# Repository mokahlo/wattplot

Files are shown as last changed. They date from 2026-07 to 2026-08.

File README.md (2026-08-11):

# Wattplot







**One bed. Two harvests.**

A raised garden bed whose canopy is a working solar panel — the same
square foot grows tomatoes *and* generates electricity. Symbiosis of
energy production and agriculture: the plants get filtered afternoon
shade where they need it most; the panel keeps generating on a
structure that would have been lumber anyway.

Open-source end-to-end: 3D model, sun simulation, wind-load analysis,
cut lists, schematic (rev B), ESPHome firmware (v3.2), PCB layout, and
a GitHub Pages site. MIT license, no paywalls, no telemetry.

> **Status:** working prototype. The Mini v2.4 is built and running on
> the bench. The full-size build (Longi 620W) is mechanically and
> aerodynamically validated by FreeCAD 3D model + ASCE 7-22 wind
> calc + geometric shadow raycaster. Firmware v3.2 is compiled and
> ready to flash (the chip is currently wedged; see [Status &
> roadmap](#status--roadmap) below).

**Live site:** [wattplot.org](https://wattplot.org/) ·
**3D booth viewer:** [wattplot.org/booth/](https://wattplot.org/booth/) ·
**Data dashboard:** [wattplot.org/data.html](https://wattplot.org/data.html)

## Two builds, one structure

Same bed, same 72" corner posts, same panel rails — pick your tilt mechanism:

| | **Basic** | **Smart** |
|---|---|---|
| Tilt | Fixed, pinned prop strut (0/15/25/35°) | Motorized, 0–35°, linear actuator |
| Electronics | None | ESP32 controller + sensors + PCB |
| Storm response | Manual stow: pull pin, lay flat (2 min) | Auto-fold on wind, plus manual stow |
| Panel | Salvaged/upcycled panel ideal | New 620 W bifacial (or any preset) |
| Cost | **~$400–650** (salvage panel, incl. soil) | ~$1,600 |
| Time | A weekend | 10–15 hr + electronics |
| Guide | [`docs/build_basic.md`](docs/build_basic.md) | [`docs/build_guide.md`](docs/build_guide.md) |

**Start with Basic.** It's the whole idea in its cheapest form: a raised
bed that shades its crop and pays you back in watts, built with a drill
and a saw. Smart is the flagship upgrade — every Basic build has the
strut holes and pivot line to accept the actuator later.

## Status & roadmap

| Layer | State | Notes |
|---|---|---|
| 3D model | ✅ Validated | FreeCAD assembly, STEP+STL+FCStd export. 5 panel presets. |
| Sun simulation | ✅ Validated | `analysis/sun_simulator.py` — annual kWh, daily DLI, tomato yield. |
| Wind load | ✅ Validated | ASCE 7-22, Cat II 700-yr, Exp C, Phoenix. |
| Cut lists | ✅ Validated | `models/cut_list.py` — every board, every cut. |
| Mini v2.4 (electronics) | ✅ Built & running on bench | 18×14″, 10W panel, kickstand actuator, ESPHome firmware. |
| Full-size structural (Basic) | ✅ Designed | 8×5 ft bed, no electronics. Weekend build. |
| Full-size Smart (electronics) | 🟡 Firmware ready, chip wedged | Schematic rev B + firmware v3.2 compiled; needs physical BOOT+RESET. |
| Custom PCB | ✅ Designed | Schematic + PCB layout. JLCPCB-ready. |
| GitHub Pages site | ✅ Live | Dark theme, 10+ pages, 3D viewer, data dashboard, gallery, diagrams. |
| Booth materials | 🟡 Mid-refresh | One-pager + FAQ + poster + sim ready; needs new symbiosis framing. |
| Trademark (WattPlot name) | 🟡 Coexistence request drafted | `docs/_internal/COEXISTENCE_REQUEST.md`. Awaiting Andrew Welch's reply. |

What this means in practice: the design is complete, the documentation
is live, the firmware builds clean. The two remaining "blocked" items
are (1) recovering the wedged ESP32-S3 so we can flash v3.2, and
(2) hearing back from the WattPlot.com operator on whether coexistence
on the name is OK.

## Design rules (enforced)

Three constraints guide every part of the design:

1. **No miter cuts.** Every cut is a 90° square cut. Joints are butt, half-lap,
   or lap. (You don't need a miter saw.) *Caveat: post lateral bracing is
   still unresolved precisely because the conventional answer needs miters -
   see "Open structural questions" below.*
2. **All hardware off the shelf.** Hinges, panel clamps, bolts, screws, rod, and
   pins are standard sizes from Home Depot, McMaster, or solar-mounting
   suppliers (IronRidge / Unirac / Quick Mount). No custom metal parts.
3. **Simple, common dimensions.** All lumber from standard stock lengths (8 ft,
   10 ft, 12 ft) with reasonable waste. No fractional-inch stock lengths.
   96" panel rails (2x6x8ft, no waste), 72" corner posts (4x4x8ft, 24"
   waste), 89"/37.6" wall skin between the posts (1x6x8ft cedar).

## Interactive 3D model

[**Open the 3D viewer**](https://wattplot.org/) - drag to orbit, scroll to zoom. Loads the live STEP-derived STL.

---

## See it at Maker Faire Bay Area 2026

**Sept 25-27, 2026 · Mare Island Naval Shipyard, Vallejo CA.**

A working Mini v2.4 on the table, 24" live-sim dashboard next to it,
printed poster, take-home cut-list cards. The booth package
(booth plan, demo script, FAQ, parts list, interactive viewer, sim
dashboard) lives in [`booth/`](booth/).

If you're at the faire, come by. If you want to exhibit your own
agrivoltaic / solar / smart-garden project, the booth package
documents what worked (and what to skip) for next time.

---

## Fits any panel up to 8×5 ft: bring your own

A single Wattplot planter is bounded by **8-ft lumber stock**: 8 ft
long, 5 ft wide. The bed is sized to the panel (with up to 0.5"
overhang per side), and the cut list is derived from the bed.

A Wattplot is, at heart, an example of **symbiosis between energy
production and agriculture**: the same square foot grows tomatoes
*and* generates electricity, because the panel that shades the crop
is the panel that powers the irrigation. The structure would be
lumber either way; the panel is what turns a planter into a power
plant.

A natural fit is to use **decommissioned rooftop panels that
would otherwise be landfilled** — a 12-year-old 250 W residential
panel is still a 235 W panel, perfectly useful for shade plus some
power, and you delay recycling by 10–20 years. The design supports
both new and salvaged panels; "bring your own."

Five validated panel presets are in `wattplot_params.py`:

| Preset | L × W (in) | New W | Derated W |
|---|---|---|---|
| `longi_620W` (new bifacial) | 97.0 × 44.6 | 620 W | 620 W |
| `residential_60cell` | 65.0 × 39.0 | 250 W | 235 W (12 yr) |
| `residential_72cell` | 77.0 × 39.0 | 300 W | 288 W (8 yr) |
| `commercial_96cell` | 65.0 × 41.0 | 400 W | 388 W (6 yr) |
| `large_format_1m65` | 65.0 × 41.0 | 400 W | 392 W (4 yr) |

```python
import wattplot_params as P
P.apply_panel_preset('residential_60cell')  # bed resizes automatically
```

For custom panels, set `PANEL['L_in']`, `PANEL['W_in']`, `wattage`,
`panel_age_years`, `panel_bifacial`, and the bed + derated wattage
are computed for you. See [`docs/upcycling.md`](docs/upcycling.md)
for the full guide (lumber math, MPPT sizing, when a salvage
panel is *not* a good fit).

---

## Build photos

The Mini v2.4 build is on the bench (see Status table). Photos of the full-size
build will go in `renders/build_photos/` once the full-size prototype exists;
until then, the booth package in [`booth/`](booth/) has the wood-frame renders
that represent the as-designed geometry. The template below describes the
shot list once a physical build is in hand.

**Build the entire apparatus:** see [`docs/build_guide.md`](docs/build_guide.md) for
the step-by-step assembly guide (8 phases, ~10-15 hours). *(Note: this doc is
written for the v2 architecture; treat it as design intent and cross-check
against `firmware/wattplot.yaml` for the current pin map and entity names.)*

**Test & validation:** see [`docs/test_checklist.md`](docs/test_checklist.md) for
per-component and per-system tests, with a final sign-off checklist. *(Same
staleness caveat as `build_guide.md`.)*

**Photo template** (for the build log):

| # | Subject | Angle | Notes |
|---|---|---|---|
| 1 | Overview of completed build | Iso from southeast, 20° elevation | Frame at 35° tilt, full bed |
| 2 | Bed close-up | Front (south wall) | Show 1x6 skin over 2x4 cleats, 2x4 header |
| 3 | Post-to-rail joint | Iso from north | Show 4x4 post top + 2x6 rails |
| 4 | Hinge detail | Side, 12" away | One hinge in close-up, show leaf + knuckle + 1⁄2" pin |
| 5 | Actuator mount | Side | 2x6 PT clevis on north rail, 2x6 wall block, 1⁄2" pin |
| 6 | Panel mounting | Above, looking down | 6× aluminum mid-clamps on the rails |
| 7 | PCB in enclosure | Above, enclosure open | JST-XH connectors, ESP32-S3, DRV8871s, INA219s visible |
| 8 | Wiring close-up | Side, 6" away | Cable carrier with motor + actuator leads |
| 9 | Soil sensors | Soil cross-section | DS18B20 + soil moisture in the bed |
| 10 | Soil filled + planted | Front | 4 tomato seedlings, 11.25" soil depth |
| 11 | Dashboard on phone | Phone in hand | HA dashboard showing tilt, motor current, panel power |
| 12 | Canopy at 35° (max tilt) | Iso from east | Power mode, structural max |
| 13 | Canopy flat (storm) | Iso from east | Folding mode, stowed |

Add your photos to `renders/build_photos/` and link them in this section.

---

---

## What's in the box

```
wattplot.py                            ← top-level pipeline:  python wattplot.py
wattplot_params.py                     ← single source of truth for ALL parameters
models/
  freecad/                             ← FreeCAD parametric 3D model (authoritative)
    materials.py                       ← wood species, fasteners, hardware
    parts/                             ← one file per part (bed_wall, frame,
      _helpers.py, bed_wall.py,        ←   hinge, panel_clamp, actuator_mount,
      frame.py, panel.py, hinge.py,    ←   skids, diagonal_brace, ...)
      panel_clamp.py, skid.py,
      actuator_mount.py
    assemble.py                         ← imports all parts, exports STEP+STL+FCStd
    _run.py                             ← freecadcmd entry point
  openscad/                             ← OpenSCAD text model (no GUI, no Python)
    wattplot.scad                       ← full assembly, 35° tilt, LONGi preset
    wattplot_params.scad                ← mirror of wattplot_params.py (CI parity)
  shadow_raycaster.py                  ← geometric bed-shadow from 3D panel
  render_3d_views.py, render_svg_views.py
analysis/
  sun_simulator.py                     ← annual kWh, bed DLI, tomato yield
  wind_load.py                         ← ASCE 7-22 force + safety factors
  engineering_drawing.py               ← side-view engineering drawings
  pcb_schematic.py                     ← PCB block-diagram generator
renders/                               ← generated PNGs (mostly gitignored)
firmware/                              ← ESPHome firmware for the controller
docs/                                  ← design + build + test docs (see below)
  index.html                           ← GitHub Pages 3D viewer
  control_law.md                       ← firmware spec (state machine, PI loop)
  pcb_design.md                        ← custom PCB spec (KiCad-ready)
  wiring.md                            ← pin-by-pin wiring from PCB to apparatus
  sensor_placement.md                  ← where each sensor mounts + why
  build_basic.md                       ← Basic tier: fixed pinned tilt, no electronics
  build_guide.md                       ← step-by-step build (8 phases, ~10-15 hours)
  test_checklist.md                    ← per-component + integration tests
  watering.md                          ← smart planter: sensors + solenoid + automation
  logging.md                           ← v2.5: MQTT log streaming to wattplot.log
```

**All design rules, the build, the wiring, and the tests are documented.**
`wattplot_params.py` is the single source of truth - change a value there
and the whole pipeline (3D model, shadow, sun sim, wind sim) updates in
~10 seconds.

---

## The design (one paragraph)

An 8 ft × 3.7 ft planter with 27.5" walls (29" rim height — top of the
wheelchair-accessible seated-gardening range, with access from both long
sides) holding 25.5" of soil, carrying a solar panel on four 72" 4x4
corner posts (walk-under canopy). The panel sits on 2x6 rails laid
across the post tops and tilts about its long axis. The bed is the
**ballast** - no ground anchors. In the **Basic** build the panel rests
on a pinned 2x4 prop strut (fixed tilt, set by hand). In the **Smart**
build it's driven by a linear actuator (0-35°; storm fold = flat), and
the controller uses a PI loop on motor current to reduce tilt under
wind load, then returns to the commanded angle when wind drops.

**35° is the structural max, and the post height is why.** Raising the
canopy to 6 ft puts panel drag on a ~6 ft lever arm about the bed edge -
roughly 3× the moment of a bed-level panel. At 35° the structure holds
SF 2.55 against overturning; 45° drops to 1.89 and 90° to 1.26, both
below the 2.0 target. The old 90° "sun-on-bed / wring-out" modes are
retired - to give the bed full sun, stow the panel flat instead.

**Frame material:** all lumber for sustainability (FSC Douglas Fir where
available). Hardware (hinges, panel clamps) is metal where the load demands.

## Power architecture - only two sources

```
            ┌─────────────────┐
            │ 620W bifacial   │
            │ main panel      │  ← the only solar source
            └────┬────────────┘
                 │  DC bus (30-40V, 0-18A)
        ┌────────┴────────┐
        │                 │
        ▼                 ▼
  ┌──────────┐      ┌───────────────────┐
  │ Micro-   │      │ MPPT (Victron     │
  │ inverter │      │  100/30 or EPEver  │
  │ (AC out) │      │  Tracer 4210AN)   │
  └────┬─────┘      └────────┬──────────┘
       │                     │
       ▼                     ▼
   [240V AC]            ┌──────────┐
                        │ 12V      │  ← the only battery
                      │ LiFePO4  │
                      └────┬─────┘
                           │
                           ▼
                    ┌──────────────┐
                    │  ESP32 +     │
                    │  DRV8871     ├──► Linear actuator (panel tilt)
                    │  BMI160 IMU  │     ↑ closed-loop position
                    │  INA219      │     │ actual tilt
                    │  DS18B20     │     │
                    │  soil sensor │
                    └──────────────┘
```

**Only two energy sources: the main 620W panel and the 12V battery.** No separate trickle panel. The main panel feeds both the microinverter (for AC) and a real hardware MPPT (Victron SmartSolar 100/30 or EPEver Tracer 4210AN) for 12V battery charging - both from the same panel via a Y-splitter on the MC4 leads. The 620W panel produces 50-100× more energy than the controller needs, so it's a non-issue.

> **Earlier revisions (v2.0-2.3) used a DPS5005 programmable buck + UART-MPPT pattern** for the full-size build. That was retired: the DPS5005 was a hack (using a bench PSU as a charge controller) and was also undersized for the 620W panel (5A max output would have thrown away ~90% of the panel's potential). The mini build (v2.4) uses a standalone **Sunapex 10A** MPPT - no host connection, IP67 waterproof, LiFePO4-aware out of the box. The full-size build needs the larger Victron/EPEver above. See `docs/build_guide.md` §7.

## Key design numbers (Phoenix, AZ, Cat II 700-yr, Exp C)

- **Wind:** 115 mph 3-sec gust design. At 25.5" soil fill (~4,800 lb dead
  load in the 27.5"-wall bed), the structure passes safety factor ≥ 2.0 from
  0-35° tilt — 35° is the max operating angle, set by the 72" post height.
  **Rated deployed wind: ~130 mph at 35°.** Stowed flat (0°) the panel
  carries no drag or uplift and only the posts are loaded (SF 26.8); stow is
  the storm answer for both tiers (manual pin on Basic, auto-fold on Smart).
  The bed depth is set by dry-soil risk: at 4 wall courses a bone-dry bed
  falls to SF 1.53, so the build ships 5 courses.
- **Power (azimuth tracking 35° tilt, Phoenix 2025):** 2,240 kWh/year.
- **Tomato yield (35° tilt):** ~84 kg/year from 4 plants (the sun
  simulator caps at 83.8 kg at 35° tilt, seasonal 90/35°, and
  azimuth tracking 35°; the 90° "bed sun" schedule gives 52.7 kg
  with much more heat stress and ~63% less power).
- **Best balance:** static 35° or azimuth tracking 35°, depending on whether
  you value simplicity or kWh.

See `analysis/wind_load_report.md` and `analysis/sun_simulator.py` for the
underlying calculations.

### Open structural questions

Raising the canopy onto 72" posts solved the walk-under/reach-under
problem but opened two checks. Both are now analyzed — and the first one
**fails** as currently specced:

1. **Post bending.** `analysis/post_bending.py` checks the 4x4 posts as
   cantilevers carrying panel drag at their base connection (the wind
   analysis in `analysis/wind_load.py` only checks the structure tipping
   as a rigid body — a separate failure mode). **Result: FAIL at the 35°
   operating cap** (SF 0.65 vs. target 1.5, worst-case load sharing).
   Unbraced, the real bending-safe tilt limit is closer to 20° than 35°.
   Two remedies, either sufficient: **(A)** upsize to 6x6 posts (SF 2.53,
   passes with margin) or **(B)** add lateral bracing (below) and confirm
   the residual base moment fits a standard bracket. See
   `analysis/post_bending_report.md` for the full numbers.
2. **Lateral bracing.** A 6-ft post-and-beam frame needs diagonal
   bracing. The retired panel-frame diagonal doesn't apply here, and the
   obvious knee brace wants 45° miters, which collides with design rule
   #1 (no miter cuts). **Square-cut gusset plates are the answer** — a
   square-cut brace (or a plywood/steel gusset alone) bolted flat across
   the post/rail corner carries the same axial force a mitered brace
   would, with zero non-90° cuts. Sized in `analysis/post_bending.py`
   (§Bracing): ~335 lb axial demand at the 35° cap, spec target ≥ 500 lb
   — well within off-the-shelf structural angle brackets.

**Do not build the full-size Smart tier with 4x4 posts, unbraced, at
35° tilt** until one of the two remedies above is locked in. Both are
tracked before any full-size build; this is a first-pass calc, not a
stamped one — get a PE review before anything goes in the ground.

## The smart controller (target design)

**Every priority is clamped to θ_max = 35°** (the structural cap — see
[`docs/control_law.md`](docs/control_law.md)). The old 90° "wring-out"
and "bed-sun" modes are retired: to give the bed full sun or dry it out,
stow flat at 0° instead, where the panel shades nothing and carries
~zero wind load.

```
priority  source                              sets θ_desired / lights
─────────────────────────────────────────────────────────────────
   1      user override                       arbitrary 0-35
   2      hard current limit                  θ = 0 (safety)
   3      NWS rain forecast + dry soil        θ = 0 (capture rain)
   4      NWS wind forecast > 50 mph          θ = 15 (preemptive)
   5      wind ≥ 50% of I_safe                pause tracking
   6      soil wet 72h+                       θ = 0 (stow flat, sun dries bed)
   7      soil dry 48h+ + no rain → conserve  θ = 35
   8      time-of-day + tracking mode         θ = 0-35 (azimuth track, capped)
   L1     battery SOC < 50%                  lights off
   L2     natural DLI > target               lights off
   L3     DLI deficit > 0 (need light)       lights on (pre/post-dawn)
   L4     hard constraint                    8 hr dark minimum
```

Goal: **keep motor current below I_safe, while maximizing commanded tilt for sun exposure.**

`docs/control_law.md` is the canonical version of this table; the firmware
enforces the 35° cap in the `commanded_tilt` number component.

## How to run

```bash
# Full pipeline (3D model export + sun sim + wind sim)
python wattplot.py

# Just the simulation (skip the 3D export)
python wattplot.py --skip-model

# Just one analysis
python analysis/sun_simulator.py
python analysis/wind_load.py

# Override a parameter at the command line
python wattplot.py --tilt 50

# View the 3D model in a browser
open renders/viewer.html
```

### Dependencies

- Python 3.10+
- `numpy`, `pandas`, `matplotlib`, `pvlib`, `shapely`, `scipy` (for analysis)
- **FreeCAD 1.0+** (for the 3D model - `freecadcmd` is auto-detected on
  Windows in `C:\Program Files\FreeCAD *\bin\`)
- `ruff` (for lint)

```bash
pip install numpy pandas matplotlib pvlib shapely scipy ruff
```

The 3D model is built by FreeCAD. On Windows with FreeCAD 1.0+ installed
in the default location, the orchestrator finds it automatically. To
override, set `$FREECADCMD` to the path of `freecadcmd.exe`.

## Hardware reference — Smart tier (target spec, not yet built)

This is the full flagship BOM. **Basic tier** deletes the actuator,
MPPT-for-controller, LiFePO4, ESP32/PCB, and grow light rows, and swaps
the new 620W panel for a salvaged one — see
[`docs/build_basic.md`](docs/build_basic.md).

| Component | Spec | ~$ |
|---|---|---|
| Bed walls | 1x6 cedar skin (5 courses, 27.5" tall) + 2x4 PT cleats + 2x4 headers; 29" accessible rim | 185 |
| Corner posts | 4 × 4x4 PT, 72" (walk-under canopy support) | 60 |
| Panel rails | 4 × 2x6 cedar, laid flat across the post tops | 45 |
| Soil | 25.5" fill ≈ 2.2 cu yd ≈ 4,500 lb (the ballast) | 160 |
| Frame rails | 2x6 PT DF, 2 × 8 ft long + 2 × 8 ft cross | 60 |
| Diagonal brace | 2x4 PT DF, 1 × 10 ft | 15 |
| Skids | 4x4 PT DF, 2 × 8 ft | 30 |
| Hinges | 4 × galvanized butt hinges 4"×4", 1⁄2" pin, +96" 1⁄2" rod | 35 |
| Panel clamps | 6 × aluminum mid-clamps, 35mm channel | 18 |
| Linear actuator | 12V, 4" stroke, IP65, 330 lb | 60 |
| **MPPT charge controller (full-size)** | Victron SmartSolar 100/30 (30A, 100V) or EPEver Tracer 4210AN (40A, 100V) | 200 |
| Panel | 620W bifacial (LONGi Hi-MO X10 or similar) | 200 |
| Microinverter | Enphase IQ7+ or APsystems DS3, 240V, UL 1741 | 150 |
| 12V 100Ah LiFePO4 | LiTime or similar | 230 |
| ESP32 + custom PCB | w/ DRV8871, INA219, BMI160, sensors | 120 |
| 200W LED grow light | full spectrum, IP65 (v2) | 130 |
| Misc (screws, bolts, wire, irrigation) | | 50 |
| **Total parts** | | **~$1,400** |

All structural lumber is FSC Douglas Fir where available. No welding. No
concrete. See `bom.md` for sourcing notes.

The MPPT is a real hardware charge controller (Victron or EPEver) sized
for the 620W panel - no firmware-side MPPT loop, no UART setpoint
commands. ESP32 reads MPPT telemetry (panel V/I, battery V, charge
state) over VE.Direct / RS-485 for energy monitoring and Home
Assistant visibility. The same panel also feeds the microinverter for
AC output via a Y-splitter. No separate trickle panel needed.

## Project status

- [x] Parametric 3D model (FreeCAD) with STEP / STL / FCStd export, one
      file per part (`models/freecad/parts/`)
- [x] All-wood perimeter frame design (2x6 rails + 2x4 brace, half-lap bed corners)
- [x] ASCE 7-22 wind load analysis, Phoenix, Exp C, Cat II 700-yr
- [x] Geometric shadow raycaster (uses actual 3D panel)
- [x] Annual sun + yield simulator (5 tilt schedules, Phoenix weather)
- [x] Engineering side-view drawings (with frame + actuator + hinge detail)
- [x] PCB spec (KiCad-ready) - `docs/pcb_design.md`
- [x] Wiring diagram (pin-by-pin) - `docs/wiring.md`
- [x] Sensor placement plan - `docs/sensor_placement.md`
- [x] Build guide (8 phases, ~10-15 hours) - `docs/build_guide.md`
- [x] Test & validation checklist - `docs/test_checklist.md`
- [x] ESPHome firmware (PI controller, NWS polling, fold logic) - `firmware/`
- [ ] Order custom PCB from JLCPCB
- [ ] Real-world deployment validation

## Prior art & acknowledgments

Wattplot builds on the work of many open-source projects. If you find their work useful, please support them.

### Agrivoltaic simulation
- **[NREL/bifacial_radiance](https://github.com/NREL/bifacial_radiance)** - gold-standard bifacial PV ray-tracer. Our 2D `shadow_raycaster.py` is a simplified version of what bifacial_radiance does in 3D.
- **[NREL/InSPIRE](https://github.com/NREL/InSPIRE)** - agrivoltaic tutorials, scripts, and research workflows.
- **[DailyAgrivoltaicOperation (astuhlmacher)](https://github.com/astuhlmacher/DailyAgrivoltaicOperation)** - dual-axis panel optimization under crop constraints, the academic version of what Wattplot does in firmware.
- **[PASE 1.0](https://gitlab.uliege.be/pase/pase_1.0)** - Python Agrivoltaic Simulation Environment, energy + crop dual-objective.

### Solar tracker controllers
- **[Helioduino (NachtRaveVL)](https://github.com/NachtRaveVL/Simple-SolarTracker-Arduino)** - mature LDR-based sun tracker for Arduino. The reference for "professional grade" tracker control.
- **[SolarArduino (HDwayne)](https://github.com/HDwayne/SolarArduino)** - ESP32 sun tracker with **wind safety using an anemometer** (folds to safety position for 15 min if wind > 5 m/s). The pattern for our wind-safety state machine in `docs/control_law.md` comes from here.
- **[Sunchronizer (Nerdiyde)](https://github.com/Nerdiyde/Sunchronizer)** - ESP32 + 6000N linear actuator + **BMI160 IMU for closed-loop position feedback**. We adopted the IMU approach for the same reason (drift-free actual tilt angle).
- **[f2knpw/ESP32_Solar_Tracker](https://github.com/f2knpw/ESP32_Solar_Tracker)** - Lite ESP32 solar tracker with sun-position calc, sleep mode, OTA.

### Smart solar chargers (MPPT pattern)
- **Earlier revisions of Wattplot (v2.0-2.3) used a DPS5005-as-MPPT pattern** (similar to OSPController and fugu-mppt-firmware below). This was retired in v2.4 because the DPS5005 was both a hack (using a bench PSU as a charge controller) and undersized for the 620W panel. The current build uses off-the-shelf hardware MPPTs (Sunapex HC-SM10A on the mini, Victron/EPEver on the full-size) - the firmware no longer commands a charge controller, it only reads telemetry.
- **[OSPController (Open Solar Project)](https://github.com/opensolarproject/OSPController)** - ESP32 controls a commercial DPS5005 buck via UART for MPPT. Good reference if you want to revive the UART-MPPT pattern (e.g., to add telemetry from a Victron VE.Direct port to a custom control loop).
- **[fugu-mppt-firmware (fl4p)](https://github.com/fl4p/fugu-mppt-firmware)** - ESP32 MPPT firmware, 95% efficient synchronous buck. Reference for designing a custom MPPT from scratch (we deliberately chose not to).
- **[akgang ESP32 MPPT](https://github.com/akgang-rgb/ESP32-Smart-Solar-Controller-MPPT-Firmware-Web-Dashboard)** - single-file Arduino ESP32 MPPT with INA226, web dashboard, NASA POWER + OWM forecasts. Reference for the MPPT loop algorithm (perturb-and-observe with dither) if we ever need to bring back a firmware-side MPPT step.

### Weather + solar (IoT pattern)
- **[SolarWS (BeardedTinker)](https://github.com/BeardedTinker/SolarWS)** - ESPHome weather station, deep sleep at night, OTA.
- **[solar_weather (squidpickles)](https://github.com/squidpickles/solar_weather)** - ESPHome config for solar weather station.
- **[Home Assistant Forecast.Solar integration](https://www.home-assistant.io/integrations/forecast_solar/)** - built-in solar production forecast for HA. A drop-in alternative to our NWS-based forecast.

### DIY raised bed + solar
- **[POSCAS](https://www.appropedia.org/Parametric_Open_Source_Cold-Frame_Agrivoltaic_Systems)** - Parametric Open Source Cold-Frame Agrivoltaic System. **The closest analog to Wattplot** in philosophy (open-source, parametric, agrivoltaic) but for a cold frame. Worth studying.
- **[Vege Garden Automation (Rototron)](https://www.rototron.info/projects/micropython-vegetable-garden-automation-tutorial/)** - solar-powered soil sensors + MQTT + HA on a raised bed. **Validates the IoT + raised bed + solar pattern** Wattplot uses.

### Standards
- **[ASCE 7-22](https://www.asce.org/publications-and-news/asce-7)** - wind load provisions. Our `analysis/wind_load.py` uses ASCE 7-22 Table 26.10-1 for velocity pressure exposure coefficients.
- **[pvlib](https://pvlib-python.readthedocs.io/)** - solar position + clear-sky modeling. Industry standard, NREL-developed.
- **[IEC 61215 / UL 61730](https://en.wikipedia.org/wiki/Solar_panel)** - panel safety standards. Our 620W bifacial panel is certified to these.
- **[UL 1741 / IEEE 1547](https://en.wikipedia.org/wiki/UL_1741)** - grid-tie inverter safety. We use a commercial microinverter (Enphase IQ7+, APsystems DS3) that meets these, so the user doesn't have to.

### Plug-and-play solar laws (regulatory)
- **Utah [SB 190](https://le.utah.gov/~2024/bills/sbillint/SB0190.html)** (2024) - first comprehensive balcony solar law, 800W plug-in allowance.
- **California [AB 1076](https://leginfo.legislature.ca.gov/faces/billNavClient.xhtml?bill_id=202120220AB1076)** (2022) - most generous, 5 kW plug-in allowance.
- **Colorado [HB 22-1015](https://leg.colorado.gov/bills/hb22-1015)** (2022) - 800W plug-in, similar to Utah.

Wattplot's 620W panel is below the 800W threshold in Utah and Colorado, and well within California's 5 kW cap. Design fits the regulatory window for plug-and-play solar in all three states.

### Tools we use
- **[cadquery](https://github.com/CadQuery/cadquery)** - parametric 3D model
- **[shapely](https://shapely.readthedocs.io/)** - 2D geometry for the shadow raycaster
- **[cairosvg](https://cairosvg.org/)** - SVG → PNG rendering
- **[matplotlib](https://matplotlib.org/)** - plots
- **[three.js](https://threejs.org/)** - the interactive 3D viewer in `docs/`

---

## License

This project is licensed under the **MIT License** - see [LICENSE](LICENSE).

You are free to use, modify, and sell products based on this design. Attribution appreciated.

## Contributing

Issues, PRs, and forks welcome. See [CONTRIBUTING.md](CONTRIBUTING.md)
for the workflow, conventional-commit style, and how to run the
firmware + analysis test suite locally. Pre-commit hooks (ruff +
the firmware pytest smoke) run on every commit.

If you build one, send photos.

## What this isn't

- **Not a turn-key product.** No PE-stamped design, no UL-listed
  inverter, no warranty. You build it; you own the risk.
- **Not a replacement for an electrician.** The LiFePO4 / MPPT /
  microinverter chain needs to be installed per local code. See
  [disclaimers.html](docs/disclaimers.html) §5.
- **Not certified for sale.** MIT-licensed hardware with no
  regulatory pathway. Selling units requires your own compliance
  work (UL 61730 for the panel, UL 1741 for the inverter, NDS / PE
  review for the structure).
- **Not a "smart solar tracker" product.** It's a single-axis
  tilt actuator with a 35° structural cap, not a dual-axis
  tracker. The "azimuth tracking" schedules in the sun simulator
  are sim-only — no firmware implements them yet.
- **Not a replacement for an off-grid solar kit.** No battery
  monitoring app, no remote firmware updates beyond ESPHome's
  OTA, no commercial support.
- **Not free of upfront work.** The Mini v2.4 has ~3-4 hours of
  build time + a custom PCB order. The full-size has 10-15 hours
  + a PE review.

## Acknowledgments

- `pvlib` (Sandia / pvlib-team) for solar position + clear-sky modeling
- `cadquery` for parametric CAD
- `shapely` for 2D geometry
- ASCE 7-22 for the wind provisions
- The "balcony solar" laws in Utah (SB 190), California (AB 1076), and Colorado (HB22-1015) for inspiring the plug-and-play direction

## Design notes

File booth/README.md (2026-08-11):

# Wattplot, Maker Faire Bay Area 2026, Booth Package

> **Show:** Sept 25–27, 2026 (Fri–Sun), 47 days from today (2026-08-09).
> **Venue:** Historic Mare Island Naval Shipyard, Vallejo CA.
> **Booth:** 10×10 ft (typical BA Faire Maker space).
> **Demo shape:** Working Mini v2.4 on a table, 24" live-sim screen next to it,
>   printed poster, take-home cut-list cards.
>
> **Project week: W3 of 9.** Mini is built and on the bench. Calibrating
> IMU + running closed-loop tilt tests this week. Collateral (poster,
> cards) prints W4. Dry runs W5–W7. Travel/pack W8. Final fixes W9.

## Why this booth

- **The story is optimization.** Two outputs — tomatoes and kilowatt-hours
  — from the same square foot. The panel canopy is what the frame would
  have been lumber for anyway, so the bed is doing more work, not the
  panel displacing the garden. (Sustainability angle: ~10M tons of solar
  panel waste by 2050, and a Wattplot gives any decommissioned panel a
  job. Strong hook for the Maker Faire audience without being the lead.)
- **Mini v2.4 fits the 10×10 footprint** (it's 18×14×12 inches on a table).
- **It's fully functional**, not a render: real panel, real MPPT, real
  actuator, real sensors, real soil. The "wow" moment is a kid pressing a
  button and the panel tilting to follow the sun.
- **Fits any panel up to 8×5 ft**, bring your own 60-cell, 72-cell,
  commercial 96-cell, or new bifacial. Five validated presets, with
  custom-panel support. See `docs/upcycling.md`.
- **Open-source, code-first**, every part of the build is in the repo.
  This is the "ask" for a Maker Faire audience.

## What's in this directory

| File | What it is |
|---|---|
| `PARTS_STATUS.md` | What's already on hand vs. what to order this week. **Order ASAP, build before the faire.** |
| `DEMO_SCRIPT.md` | The 30-second, 2-minute, and 5-minute booth script. What to say, what to point at, what to press. |
| `FAQ.md` | Anticipated questions from faire visitors + crisp answers. |
| `ONE_PAGER.md` | The 8.5×11 take-home (markdown source, prints to PDF). |
| `CUT_LIST_CARD.md` | The 4×6 take-home, the 7 cut lengths on one card. |
| `POSTER.md` | The 24×36 poster concept (text + layout, ready for design pass). |
| `viewer.html` | Interactive 3D viewer (booth-friendly, with auto-rotate + tilt slider). |
| `sim_dashboard.html` | Live-sim dashboard: kWh, DLI, tilt, soil, wind, battery. Stand-alone, no ESP required. |

## Timeline (working backward from Sept 25)

| Week | Dates | Goal |
|---|---|---|
| W1 | Jul 23 – Jul 29 | **Order remaining parts.** Booth package foundation (this dir). |
| W2 | Jul 30 – Aug 5  | **Build the Mini v2.4** (~3-4 hrs). First flash of ESPHome. |
| W3 | Aug 6 – Aug 12  | Calibrate IMU. Closed-loop test. Fill `renders/build_photos/`. |
| W4 | Aug 13 – Aug 19 | Booth collateral: poster printed, cards printed, viewer polished. |
| W5 | Aug 20 – Aug 26 | Dry runs. Practice the demo script. Make a "backup mini" if time allows. |
| W6 | Aug 27 – Sep 2  | Rehearsals. Tighten the demo. Write the speaker notes. |
| W7 | Sep 3 – Sep 9 | Rehearse for friends. Watch for things that confuse people. |
| W8 | Sep 10 – Sep 16 | Pack list. Travel plan. Final hardware burn-in (run for 48 hrs straight). |
| W9 | Sep 17 – Sep 24 | Travel setup. Final fixes. |
| Faire | Sep 25 – 27 | **Mare Island, Vallejo.** Setup Fri 8am, open 10am. |

## Booth layout (10×10)

```
        ┌────────────────────────── 10 ft ──────────────────────────┐
        │                                                            │
        │  ┌────────────┐   ┌──────────────────────┐                 │
        │  │  POSTER    │   │  24" SCREEN          │                 │
        │  │  24×36     │   │  sim_dashboard.html  │                 │
        │  │  vertical  │   │                      │                 │
        │  └────────────┘   └──────────────────────┘                 │
        │                                                            │
        │        ┌──────────────────────────────────┐                │
        │        │  TABLE (30" deep, 6 ft wide)     │                │
        │        │  [ MINI v2.4 + sun lamp ]        │                │
        │        │  [ push-button → panel tilts ]   │                │
        │        └──────────────────────────────────┘                │
        │                                                            │
        │  [ 3D viewer on laptop, 14" ]                              │
        │  [ take-home cards stacked ]                               │
        │  [ 1-2 stools for visitors ]                               │
        │                                                            │
        └────────────────────────────────────────────────────────────┘
```

Two operators minimum (so one can always be at the table when the other
is at the poster or in the restroom). Bring a printed run-of-show with
contact numbers.

## Budget

| Item | Cost |
|---|---|
| Remaining Mini v2.4 parts (~$150 from `PARTS_STATUS.md`) | $150 |
| 24" portable monitor (used, refurbished OK) | $120 |
| Poster print, 24×36, foam-core mounted (FedEx Kinko's) | $40 |
| Take-home cards, 4×6, 500 ct (Vistaprint) | $35 |
| Sun lamp (clamp-on, for the indoor demo) | $20 |
| Pushbutton + wire (for hand-on interaction) | $5 |
| Travel + lodging (3 nights, Vallejo/SF) | $700 |
| Booth fee (already paid via `make.co`) | $0 |
| **Total** | **~$1,070** |

> If the 24" monitor is already in hand, drop that line. If a friend has
> a spare, ask. Maker Faire is the wrong place to discover your monitor
> is dead.

## Constraints (from the venue + the project)

- **No open flames, no propane, no welding.** Wood + 12V only. Easy.
- **10×10 max booth footprint.** No roof, no walls, just canopies allowed
  in some areas, check the faire rules.
- **WiFi is unreliable at Mare Island.** The sim_dashboard is a
  stand-alone HTML page that runs offline. No cloud, no streaming, no
  surprises.
- **The Mini v2.4 runs on its own battery** (12V 7Ah LiFePO4). It can
  demo for ~6 hours without a charge. The sun lamp is for the
  "indoor demo" only, outdoors the sun does the work.

## How to run the booth

1. **Arrive 2 hours before doors open.** Setup is faster than you think.
2. **Test the demo at the booth before the first visitor walks up.**
3. **30-second version** is for the casual walk-by. **5-minute version**
   is for the curious maker who wants to see the firmware.
4. **Hand every visitor a take-home card.** "Scan the QR, the build
   guide is free." This is the most important booth action.
5. **Trade contact info** with the people who say "I'm going to build
   one." Email them after the faire with the repo link and offer to
   answer questions.

See `DEMO_SCRIPT.md` for the actual talk track.

---

## Running the booth

The two HTML pages (`viewer.html`, `sim_dashboard.html`) load STL /
SVG files via `fetch()`. Chrome blocks `fetch()` over `file://`, so
serve the `booth/` directory over HTTP at the booth.

```bash
# On the booth laptop, in a terminal:
cd booth
python -m http.server 8000

# Then open:
#   http://localhost:8000/viewer.html         (3D viewer)
#   http://localhost:8000/sim_dashboard.html  (live sim)
```

> **Pre-fair checklist:** run this on the booth laptop the night
> before, take a screenshot of each, and verify they render. WiFi
> at Mare Island is unreliable, but `localhost` is local and
> always works. Do not depend on a hosted CDN at the faire
> (the 3D viewer uses `unpkg.com` for Three.js, cache the
> assets offline before you go).

### Offline-ready Three.js (recommended)

If you want to be 100% offline at the booth:

```bash
# Once, on a network connection:
mkdir -p booth/vendor/three
curl -L https://unpkg.com/three@0.160.0/build/three.module.js \
  -o booth/vendor/three/three.module.js
# (recreate the subfolders: controls/, loaders/, and copy the
#  needed .js files; ~30 small files total)

# Then edit viewer.html to use ./vendor/three/ instead of
# https://unpkg.com/three@0.160.0/
```

> Easier alternative: bring a personal hotspot. The unpkg CDN is
> small and only loads once.

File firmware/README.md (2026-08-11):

# Wattplot Controller v3.2 — ESPHome firmware

ESPHome configuration for the Wattplot controller. The single source of
truth for what the chip actually does is `wattplot.yaml` at the top of
this directory — if anything in this README disagrees with that file,
the YAML wins. This README explains the structure, the pin map, and
how to flash / tune the controller.

**Spec & math behind the state machine / PI loop:** [`../docs/control_law.md`](../docs/control_law.md)
(pinned to YAML behavior; the 10-priority decision stack described in
that doc is aspirational — only the wind-safety 4-state machine is
implemented. See `docs/_internal/` for the chip-recovery notes.)

---

## Hardware assumptions

Target hardware is **ESP32-S3-DevKitC-1-N16R8** (16 MB flash, 8 MB
PSRAM). The schematic is **rev B (2026-08-03)** — see
[`../docs/schematic.html`](../docs/schematic.html) and the pin-map
audit at [`../docs/pinmap.html`](../docs/pinmap.html). The full pin
table is at the top of `wattplot.yaml`.

| Subsystem | Component | GPIO / Bus |
|---|---|---|
| **Actuator H-bridge** (panel tilt) | DRV8871 U5a | IN1 = GPIO1, IN2 = GPIO2, EN = GPIO11 (compat-only, schematic ties EN → 3V3) |
| **Actuator IPROPI** (current sense for endstops) | ADC1_CH4 | GPIO4 |
| **Motor nFAULT** | direct GPIO | GPIO21 |
| **Solenoid H-bridge** (water valve) | DRV8871 U5b | IN1 = GPIO10, IN2 = GPIO12 (compat-only, schematic ties IN2 → GND) |
| **Solenoid IPROPI** (jam detect) | ADC1_CH5 | GPIO5 |
| **Solenoid nFAULT** | direct GPIO | GPIO13 |
| **Motor current + actuator bus V** | INA219 @ I²C 0x40 | SDA = GPIO8, SCL = GPIO18 |
| **Panel V/I** (energy monitor) | INA219 @ I²C 0x41 | same I²C bus |
| **DS18B20** (3 sensors on one bus) | 1-Wire | GPIO16, 4.7 kΩ pullup |
| **Soil moisture** (capacitive) | ADC1_CH6 | GPIO6 |
| **Battery V** (100k / 10k divider, ×11.0) | ADC1_CH7 | GPIO7 |
| **Status LED** (monochromatic, LEDC) | output | GPIO17 (compat-only, removed from rev B schematic) |
| **Frost heater** (relay drive, v3.3) | GPIO | GPIO39 (relay coil required) |
| **Frost grow light** (relay drive, v3.3) | GPIO | GPIO40 (relay coil required) |

**Reserved / unused (do not reassign):** GPIO 19, 20 (native USB);
GPIO 26–32 (SPI flash on the WROOM module); GPIO 33–37 (PSRAM on the
N16R8 variant). GPIO 39, 40, 41, 42, 47, 48 are free on the
DevKitC-1-N16R8 carrier.

**Removed in rev B, kept in firmware as compat-only stubs:** the
physical limit switches (GPIO 14, 15 — "compat-only" placeholders
that the state machine never reads), the WS2812B status LED (now a
monochromatic LEDC PWM on GPIO 17), and the MCP23017 I²C expander
(nFAULT is now direct GPIO on 13 and 21). The IDs (`actuator_nfault`,
`solenoid_nfault`, `status_led_pwm`, etc.) are preserved so the
state-machine references compile against a future re-spin.

**Charge control is out of the firmware.** The mini uses a standalone
**Sunapex 10A MPPT** (IP67, LiFePO4-aware, no host connection). The
full-size build needs a **Victron SmartSolar 100/30** or
**EPEver Tracer 4210AN** (both handle the 620 W panel's ~17 A Imp).
The ESP32 only *reads* battery voltage (via the on-PCB 100k / 10k
divider on GPIO7) and panel-side V/I (via the panel INA219) — it does
not command a charge controller. This is the deliberate simplification
that replaced the v2.0-2.3 DPS5005-as-MPPT hack.

**IMU / closed-loop tilt feedback: not currently used.** The
schematic rev B removed the BMI160 footprint. `panel_tilt` mirrors
`commanded_tilt` (open-loop position) and the H-bridge uses
**current-based homing** via the actuator IPROPI pin (GPIO4): when
the panel hits a hard stop the DRV8871's internal current limit
trips, IPROPI sees a sustained ≥ 0.90 A spike, and the firmware sets
`g_at_zero` / `g_at_max` accordingly. The dead `bmi160:` block is
preserved in `wattplot.yaml` for a future MPU6050 swap-in (drop-in
I²C at 0x68, full ESPHome 2026.7 YAML support).

---

## What it does — five concurrent loops

All driven from a single YAML file (`wattplot.yaml`):

| Interval | Period | Purpose |
|---|---|---|
| `control_loop` | 1 s | State machine: NORMAL → MONITORING → FOLDING → LOCKED. PI loop on motor current. |
| `nws_poll_interval` | 15 min | Pulls NWS forecast; populates globals (`g_nws_max_wind_mph`, `g_nws_rain_forecast`). *Note: the 1 Hz loop does not currently read these globals; the wind-event state transitions are triggered by motor current only.* |
| `dli_update` | 5 min | Integrates PAR over the day; the `grow_light_tick` reads this to decide if the solenoid should run in auto mode. |
| `energy_integration` | 1 s | Sums panel V × I → `Energy Today`, `Energy Total`. |
| `endpoint_detector` | 100 ms | Looks for the IPROPI current spike that signals end-of-travel. |
| `grow_light_tick` | 60 s | Auto-water logic (the "grow light" name was retained from when this drove a light; the load is now a 12 V solenoid valve). |
| `frost_tick` | 60 s | v3.3 frost protection: reads soil + canopy temps, applies threshold/hysteresis/watchdog/battery-floor, drives `frost_heater_sw` and/or `frost_grow_light_sw` per `Frost Mode`. See [`../docs/frost_protection.md`](../docs/frost_protection.md). |
| `alive_tick` | 5 s | DEBUG ping only (does not gate actuation). |

State machine and tuning constants are exposed in Home Assistant as
`number:` and `select:` entities — no re-flash needed for routine
tuning.

---

## Quick start

### 1. Install ESPHome CLI

```powershell
pip install esphome
```

Verify:

```powershell
esphome version
```

ESPHome version is pinned loosely — `wattplot.yaml` declares
`min_version: 2024.6.0`; anything past that with current sensor/INA219
support works. (Note: the disabled `bmi160` block and several
component migrations were last validated against ESPHome 2026.7.2.)

### 2. Create your secrets file

```powershell
cd C:\dev\wattplot\firmware
Copy-Item secrets.yaml.example secrets.yaml
```

Open `secrets.yaml` and replace every `CHANGE_ME_*` / `YOUR_WIFI_*`
value. For `api_encryption_key`, generate a fresh one:

```powershell
python -c "import secrets,base64; print(base64.b64encode(secrets.token_bytes(32)).decode())"
```

### 3. Flash the device

Wire the ESP32-S3 to USB and run:

```powershell
esphome run wattplot.yaml
```

ESPHome will:
1. Compile the firmware.
2. Detect the serial port.
3. Upload to the chip (first time requires USB; later you can use
   OTA).
4. Start streaming logs (`Ctrl+C` to exit, device keeps running).

If the chip is wedged (the recovery procedure for this is in
`docs/_internal/esp32-s3.md` §8):

```powershell
python -m esptool --chip esp32s3 --port COM## --before no-reset --after watchdog-reset --baud 460800 write_flash 0x0 firmware\.esphome\build\wattplot-controller\build\firmware.factory.bin
```

### 4. Watch the logs

```powershell
esphome logs wattplot.yaml
```

You should see a v3.2 boot banner:

```
[boot] === Wattplot v3.2 ===
[boot]   build:       Aug  6 2026 16:55:00
[boot]   reason:      0
[boot]   free heap:   1234567 bytes
[state:to_folding] Hold position during boot
[endpoint:099] Extended 0° — g_at_zero SET
```

If the controller state shows `Folding` at boot, that's intentional —
the safe default is to wait for valid INA219 reads before trusting
actuator motion.

### 5. Adopt in Home Assistant

The ESPHome integration auto-discovers the device. Click **Configure**
in HA → Settings → Devices & Services. Use the same
`api_encryption_key` from `secrets.yaml` if prompted.

---

## Customization without re-flashing

All tuning constants and the controller mode are exposed as HA
entities:

| Entity | Type | Default | Effect |
|---|---|---|---|
| `number.target_current` | A | 0.50 | Motor-current PI setpoint |
| `number.i_safe` | A | 2.50 | Hard fold if motor current exceeds `i_safe + 0.3` |
| `number.deadband_a` | A | 0.15 | No PI update if `|I - target| < deadband` |
| `number.commanded_tilt` | ° | 35 | Target tilt in NORMAL state (structurally capped at 35° per `analysis/wind_load.py`) |
| `number.kp_value` | deg/A | 2.0 | PI proportional gain |
| `number.ki_value` | deg/(A·s) | 0.10 | PI integral gain |
| `number.max_step_per_sec` | °/s | 3.0 | Actuator slew-rate cap |
| `number.solenoid_max_water_sec` | s | 300 | Force-off the solenoid after this continuous on-time (safety guard) |
| `number.battery_water_floor_v` | V | 11.5 | Don't water if battery V is below this |
| `number.one_off_water_sec` | s | 5 | Duration of the "Water Now" button press |
| `number.endstop_current_threshold` | A | 0.90 | IPROPI threshold for end-of-travel detection |
| `select.controller_state` | — | Folding | `Normal` / `Monitoring` / `Folding` / `Locked` |
| `select.controller_mode` | — | Power | `Power` only — `BedSun` (90°) was retired (fails the wind calc at design wind) |
| `select.grow_light_mode` | — | Off | `Off` / `Auto` / `Manual` (the "grow light" name is historical; the load is now a 12 V solenoid valve) |
| `switch.solenoid_valve` | — | off | Toggle the solenoid manually |
| `button.water_now` | — | — | One-shot pulse (`one_off_water_sec`) |
| `button.calibrate_actuator` | — | — | Run the actuator self-calibration (zero + max endstop discovery) |

If you want to change the **state machine** or **decision stack**
itself, edit the YAML. After editing:

```powershell
esphome run wattplot.yaml        # compile + upload (OTA if reachable)
esphome logs wattplot.yaml       # follow logs
```

---

## Decision stack (what's actually implemented)

The control loop (1 Hz `control_loop` interval) implements only the
**wind-safety state machine** from `docs/control_law.md`. The
10-priority "sun + soil + rain + wind + user" decision stack
described in that doc is aspirational — globals for NWS wind/rain
exist, but the 1 Hz loop does not yet read them. Today's behavior:

1. **Motor current > `i_safe + 0.3`** → fold (override everything)
2. **Actuator nFAULT persistent > 2 s** (DRV8871 internal ITRIP trip) →
   fold
3. Otherwise the 4-state machine runs:
   - **NORMAL** → PI loop drives tilt to `commanded_tilt`
   - **MONITORING** → entered when `i_motor > 0.5 * i_safe` (i.e. the
     wind is loading the panel); 15-min countdown to either resume or
     fold
   - **FOLDING** → retract actuator to 0° (stow flat)
   - **LOCKED** → 30-min hold at 0°; exit on `i_motor < 0.3 * i_safe`
     for a single 1-Hz sample
4. **State on boot: FOLDING** (`controller_state.initial_option`,
   `on_boot` script runs `state_to_folding`)

The "5-min settle" and the SOC-based light gating described in
`docs/control_law.md` are not implemented yet. Full math + edge cases
in [`../docs/control_law.md`](../docs/control_law.md) — but treat the
doc as design intent, not a literal description of today's behavior.

---

## Troubleshooting

| Symptom | Likely cause | Fix |
|---|---|---|
| Battery not charging | Sunapex wiring (panel MC4 polarity, battery polarity) or Li mode not selected | Red MC4 → Sunapex PV+ (via SAE), black MC4 → Sunapex PV−; battery + to BAT+, − to BAT−; press MODE button until LCD shows "Li" or "LiFePO4" |
| Sunapex LCD blank | No battery connected (Sunapex is powered by the battery, not the panel) | Connect battery first, then panel |
| `INA219 not detected` at 0x40 / 0x41 | Missing chip on I²C bus, SDA/SCL swapped, or no pullups | Both INA219s must be present before flashing — `esphome config` will fail with a clear I2C error if either is missing |
| `actuator_nfault` ON in logs (and stays > 2 s) | DRV8871 internal current limit tripped (panel jammed, stuck at endstop) | Check mechanical path; run `button.calibrate_actuator` to re-discover endpoints |
| Chip wedged, won't enter SPI Boot mode | The DevKitC-1's native USB-Serial/JTAG has no DTR/RTS reset; esptool's default `--after hard-reset` is a no-op | Use `--after watchdog-reset`. Full procedure in `docs/_internal/esp32-s3.md` §8 |
| `Panel Power` sensor is 0 W | Panel-side INA219 not installed, or panel in shade | Confirm second INA219 at I²C 0x41; check Sunapex LED shows charging |
| Solenoid won't run in Auto | `grow_light_mode` is `Off`, or battery V < `battery_water_floor_v`, or `solenoid_fault_alarm` is latched | Switch to `Auto`; check `Battery Voltage` and `Solenoid Fault Alarm`; latch clears on next fault-free tick |
| Solenoid turns off after 5 min on `Manual` | `solenoid_max_water_sec` safety guard | Expected. Raise the number, or switch to `Auto` for demand-driven watering |
| Wi-Fi not connecting | Wrong SSID / password | Edit `secrets.yaml`, re-run `esphome run` (USB) |
| Canopy won't fold under wind | `i_safe` too high OR NWS poll failing (and the wind-event path is motor-current-based anyway — see Decision stack) | Check `number.i_safe`; the wind-event state transitions are driven by motor current, not NWS wind forecast, in the current firmware |

---

## OTA updates

Once the device is on Wi-Fi, you can push firmware updates over the
network:

```powershell
esphome upload wattplot.yaml --device wattplot.local
```

ESPHome uses mDNS (`wattplot.local`) and falls back to the IP if mDNS
is blocked. You'll be prompted for `ota_password` (from `secrets.yaml`).

---

## Files

```
firmware/
├── wattplot.yaml              ← the firmware (2029 lines, single source of truth)
├── secrets.yaml.example       ← template (copy to secrets.yaml, never commit)
├── secrets.yaml               ← your real secrets (gitignored)
├── README.md                  ← this file
├── watch_boot.py              ← serial-monitor helper for the wedged-chip recovery (standalone)
├── .gitignore                 ← keeps the .esphome build cache out of git
└── tests/                     ← pytest suite (config + codegen checks)
    ├── conftest.py
    ├── test_config.py         ← pin/ID presence tests, S3 constraint guards
    └── test_codegen.py        ← lambda / generated-code regression checks
```

`firmware/logic/` is reserved for future Python reference
implementations of the lambdas (POA hour-angle, SOC lookup, etc.) — the
directory is currently empty of `.py` sources. The math is implemented
inline in the YAML; see the comments in `wattplot.yaml` for pointers.

`secrets.yaml` is in `.gitignore` at the repo root. Don't add it.

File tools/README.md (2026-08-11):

# tools/ — operator + bench + booth scripts

Every script in this directory either talks to the wattplot
controller over its native ESPHome API (port 6053), drives one of
the simulation/analysis tools, or maintains the docs site.

## Common pattern

All scripts that connect to the controller resolve the API encryption
key via `tools/_secrets.py`:

  1. `WATTPLOT_API_KEY` environment variable (recommended for CI,
     the bench PC, and the booth PC).
  2. `firmware/secrets.yaml` `api_encryption_key:` field (dev box).
  3. `~/.config/wattplot/api_key` (per-user override).

If none of the three resolves, the script fails fast at import time
with a clear `WattplotConfigError` — never at the point of use. See
`_secrets.py` for the rotation procedure if the previous hardcoded
key was leaked.

Default host: `wattplot-controller.local` (mDNS). Override with the
first CLI arg if your chip answers a different hostname.

## Live debug + bench tests

| Script | What it does |
|---|---|
| `dump_state.py` | Full state dump — every exposed entity's name, type, current value, organized into sections (power, sensors, actuator, solenoid, calibration, diagnostics). Read-only. |
| `show_state.py` | Condensed dump of the high-signal entities (controller state, commanded tilt, panel/battery voltages, fault flags). Read-only. |
| `check_soil.py` | Soil moisture sensor (raw V + percent). |
| `check_temps.py` | Panel, soil, and canopy air temperature. |
| `check_wattplot_state.py` | Lists all entities and their values. |
| `calibrate_watch.py` | Runs `button.calibrate_actuator` and watches the calibration progress: endstop current, spike duration, peak IPROPI. Logs the full timeline. |
| `run_calibration.py` | Triggers the calibration button and polls `Last MAX / ZERO Endstop Current` as they fill in. |
| `demo_tilt.py` | Sets Controller Mode to Power, commands a tilt, verifies the manual control path. |
| `test_actuator_motion.py` | Drives the actuator extend + retract with a live battery. Auto-stops on endstop spike (>0.90 A for ≥1 s) or nFAULT. Safety-bounded. |
| `test_hbridge.py` | Logic-level H-bridge test only. Drives IN1/IN2 in 4 phases (idle, fwd, rev, idle) with **no motor connected**. Confirms the firmware can drive the GPIOs and the DRV8871 is responding on its logic inputs. |
| `test_solenoid.py` | Drives the solenoid H-bridge in 3 phases (idle, 1 s ON, OFF/settle) and logs IPROPI + nFAULT. |

## Live control server

| Script | What it does |
|---|---|
| `wattplot_control.py` | aiohttp server on `127.0.0.1:8765` that proxies to the wattplot's native API and serves the control panel UI (`docs/control.html`). Exposes `/api/state`, `/api/whoami`, `/api/switch`, `/api/number`, `/api/select`, `/api/button`, `/api/logs`, plus `/logs.html`. Includes a zeroconf/mDNS discovery, a 30 s link watchdog, and a CORS allowlist for github.io reads. **Cloudflare Access is the real auth gate on the POSTs** — see `docs/_internal/remote-access.md`. |

## Logging

| Script | What it does |
|---|---|
| `log_subscriber.py` | Subscribes to `wattplot/#` over MQTT, writes every line to a daily-rotated, gzipped `logs/wattplot.log`. Keeps 30 days by default. Pairs with the Mosquitto broker setup in `docs/logging.md`. |

## Docs / site maintenance

| Script | What it does |
|---|---|
| `audit_gallery.py` | Scores every image in `docs/gallery/` on uniqueness + variance. Low scores = flat / placeholder / broken. Catches regressions when an image is deleted but the gallery tile remains (or vice versa). |
| `parse_ci.py` | One-liner: `python tools/parse_ci.py ci_run.json` — print a flat summary of job + step conclusions from a GitHub Actions run JSON. Hand-rolled; doesn't depend on any package. |
| `add_live_nav_link.ps1` | Splice the "Live ↗" button into every HTML page that has the topnav. Idempotent (skips files that already have the class). Useful if the Live URL changes. |

## What's deliberately *not* here

- **Analysis scripts** (`analysis/*.py`) — those are the simulation
  pipeline; they don't touch the live controller.
- **3D model scripts** (`models/freecad/_run.py`,
  `models/render_3d_views.py`, etc.) — those belong with the model.
- **The ESPHome firmware** (`firmware/wattplot.yaml`) — that's the
  firmware.

## Adding a new tool

1. Resolve the key via `from _secrets import get_api_key`.
2. Use `HOST = "wattplot-controller.local"` as the default.
3. Match the existing script style (top docstring describing what it
   does, an `async def main()` entry point, `if __name__ == "__main__":
   asyncio.run(main())`).
4. Add a row to the relevant table above.
5. Update `tools/README.md` (this file) in the same PR.

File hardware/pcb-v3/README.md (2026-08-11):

# Wattplot v3 — Custom PCB

**Status:** design in progress (KiCad 10.0, installing)
**Goal:** integrate every wattplot subsystem onto one 2-layer board.
No breakout boards. ~$30-50 in PCBs + assembly for 5 boards at JLCPCB.
**Replaces:** v1 block diagram in `analysis/pcb_schematic.py` (which
was ESP32-WROOM-32E based and didn't include the INA219s, DS18B20s,
or the 2nd DRV8871 that the current wattplot actually uses).

---

## What this board does

The wattplot v3 controller board is a single PCB that hosts:

1. **Power tree** — 12V (battery / MPPT) → MP1584 → 5V → AMS1117 → 3.3V
2. **ESP32-S3** — bare WROOM-1 module (not the DevKitC-1), with USB-C,
   ESD, USB-UART bridge, boot/reset buttons
3. **2× DRV8871** — actuator H-bridge (U5a) and solenoid H-bridge (U5b),
   current sensing via IPROPI, no physical limit switches
4. **2× INA219** — actuator bus current + panel V/A (energy monitor)
5. **Sensor interfaces** — 1-Wire connector (3× DS18B20 daisy chain),
   soil moisture probe connector, all on the same I²C / GPIO bus
6. **Status LED** — single LED on GPIO17 (compat pin from v1)

External (NOT on the PCB):
- MPPT (Sunapex 10A) — own enclosure
- 12V LiFePO4 battery — own enclosure
- Solar panel
- Linear actuator — mechanical
- Solenoid valve — mechanical
- DS18B20 temp probes (3×) — wired to PCB via 3-pin JST-XH
- Capacitive soil moisture probe — wired to PCB via 3-pin JST-XH

---

## Pin map (matches the current `firmware/wattplot.yaml`)

| Function | GPIO | Pin | Notes |
|---|---|---|---|
| Actuator H-bridge IN1 | GPIO1 | U5a | |
| Actuator H-bridge IN2 | GPIO2 | U5a | |
| Actuator IPROPI | GPIO4 | U5a | ADC1_CH3, current sense |
| Solenoid H-bridge IN1 | GPIO10 | U5b | |
| Solenoid H-bridge IN2 | GPIO12 | U5b | |
| Solenoid nFAULT | GPIO13 | U5b | input, 10k pull-up |
| Solenoid IPROPI | GPIO5 | U5b | ADC1_CH4, jam detect |
| Actuator nFAULT | GPIO21 | U5a | input, 10k pull-up |
| DS18B20 (1-Wire DQ) | GPIO16 | one-wire | 4.7k pull-up to 3.3V |
| Soil moisture AOUT | GPIO6 | ADC1_CH6 | |
| Battery V divider | GPIO7 | ADC1_CH6 | 100k+100k divider, midpoint to GPIO7 |
| I²C SDA | GPIO8 | I²C | 4.7k pull-up to 3.3V, shared by 2× INA219 |
| I²C SCL | GPIO18 | I²C | 4.7k pull-up to 3.3V |
| Status LED | GPIO17 | LED | 1k series, compat pin from v1 |
| USB D+ | GPIO20 | native USB | (not used, native USB on S3) |
| USB D- | GPIO19 | native USB | |
| (H-bridge EN) | GPIO11 | compat | reserved, no connection |
| Boot button | GPIO0 | BOOT | pulled up, tactile switch to GND |
| Reset button | EN | RST | pulled up, tactile switch to GND |

---

## Subsystem reference designs

### Power tree
- 12V input from MPPT LOAD via fuse (3A resettable PTC) + TVS (SMBJ 16V)
- MP1584EN buck, 12V→5V @ 3A peak (TI recommended circuit)
  - L = 4.7µH shielded, ≥ 3A saturation
  - Cin = 22µF/25V (SMD 1210)
  - Cbst = 100nF (SMD 0402)
  - Cout = 22µF/10V (SMD 1210)
  - Feedback resistors for 5V out: Rtop=33k, Rbot=10k (per MP1584 datasheet)
- AMS1117-3.3 LDO, 5V→3.3V
  - Cin = 10µF/10V (SMD 0805)
  - Cout = 22µF/10V (SMD 0805)
- Decoupling: 100nF/10V (SMD 0402) on every IC's power pin
- Battery voltage divider: 100kΩ + 100kΩ (both 1% 0402), midpoint to GPIO7

### ESP32-S3 module
- ESP32-S3-WROOM-1-N16R8 (Espressif) — 16MB flash, 8MB PSRAM
- Native USB (no UART bridge needed for programming)
- USB-C connector (16-pin SMD)
- USBLC6-2 (SOT-23-6) ESD on CC1, CC2, D+, D-
- 5.1kΩ pull-down on CC1 and CC2 (signals 3A / 1.5A current advertisement)
- 100nF caps on USB data lines (per USB spec)
- 10µF caps on USB VBUS
- Boot button: tactile switch, GPIO0 to GND (active low)
- Reset button: tactile switch, EN to GND (active low)
- 10kΩ pull-up on EN
- Status LED on GPIO17, 1k series, 0805

### 2× DRV8871 (U5a + U5b)
- DRV8871PWPR (TSSOP-28) — TI
- nSLEEP tied directly to 3.3V (always enabled)
- nFAULT: 10kΩ pull-up to 3.3V, output to ESP32 GPIO
- IPROPI: 1kΩ to GND (200mV/A conversion), output to ESP32 ADC
- VM (pin 1): 12V from MPPT, fused (3A PTC)
- VM bulk cap: 100µF/35V electrolytic + 100nF/50V ceramic, per DRV8871
- VCC (pin 3): 3.3V, decoupled with 100nF + 1µF
- BST (pin 28): 1µF to OUT1, charge pump cap
- OUT1, OUT2: to motor connector (JST-XH 2-pin for actuator, JST-XH 2-pin for solenoid)
- GND: pin 2, also exposed to power ground

### 2× INA219 (I²C current sensors)
- INA219AIDR (SOIC-8) — TI
- 0.1Ω shunt (2512 SMD, 1W) — one per INA219, in series with the rail
  - U5a INA219: measures 12V bus current to the actuator H-bridge VM
  - U6b INA219: measures panel V/A (for energy monitor)
- I²C addresses: 0x40 (U5a), 0x41 (U6b) — already used in firmware
- SDA/SCL: 4.7kΩ pull-up to 3.3V (one pair shared)
- Decoupling: 100nF + 1µF near each chip
- VIN+ to ESP32 3.3V (logic supply), VIN- floating or GND (we use VIN+ as supply)

### 1-Wire connector (DS18B20 daisy chain)
- 3-pin JST-XH connector (3.3V, DQ, GND)
- 4.7kΩ pull-up from DQ to 3.3V (on PCB, not in probes)
- DQ to GPIO16
- Up to 3 DS18B20 sensors in parallel (firmware has 2 wired so far, +1 spare)

### Soil moisture connector
- 3-pin JST-XH connector (3.3V, AOUT, GND)
- AOUT to GPIO6
- 100nF cap on AOUT to GND (noise filter)

### Connectors
- **J1 — Battery / 12V input**: XT60 (through-hole)
- **J2 — Solar / MPPT output**: MC4 or JST-XH 2-pin (input to PCB, parallel with battery)
- **J3 — Actuator motor**: JST-XH 2-pin (DRV8871 OUT1, OUT2)
- **J4 — Solenoid valve**: JST-XH 2-pin (DRV8871 OUT1, OUT2)
- **J5 — 1-Wire sensor chain**: JST-XH 3-pin (3.3V, DQ, GND)
- **J6 — Soil moisture**: JST-XH 3-pin (3.3V, AOUT, GND)
- **J7 — USB-C**: 16-pin SMD USB-C
- **J8 — Expansion header**: 2×5 pin 0.1" header (I²C, 3.3V, GND, 2× GPIO)
- **J9 — Solar bypass** (optional, not in v3): MC4 passthrough

### Test points
- TP1: +12V (after fuse)
- TP2: +5V
- TP3: +3.3V
- TP4: GND (×2, near opposite corners)
- TP5: VBAT (battery voltage, before fuse)

### Mounting
- 4× M3 mounting holes, 3.2mm pad, near corners

---

## Form factor

- **Target size:** 80×60mm, 2-layer, 1.6mm FR4 (matches v1 spec)
- **Mounting:** 4× M3 corners, 3.2mm pad
- **Connector placement:** all external connectors on the same edge
  (long edge, opposite from the ESP32 antenna) for clean wiring

---

## JLCPCB SMT component list (preliminary)

**Basic library (free):**
- ESP32-S3-WROOM-1-N16R8 (C2913203)
- AMS1117-3.3 (C6186)
- MP1584EN (C16581)
- INA219AIDR (C9459)
- 0402 resistors (1% 100k, 10k, 4.7k, 1k, 5.1k, 22)
- 0402 caps (100nF/10V)
- 0805 caps (10µF, 22µF)
- 1210 caps (22µF/25V)
- SOT-23-6 (USBLC6-2 or similar)
- Status LED (0805)
- Tactile switches
- 2512 resistor (0.1Ω 1W)

**Extended library ($3 setup per part):**
- DRV8871PWPR (TSSOP-28) — confirm availability
- SMBJ16A TVS (DO-214AA) — confirm
- MF-SMDF050 fuse (1812) — confirm
- JST-XH connectors — confirm (might be extended)
- USB-C connector (16-pin SMD) — confirm

(Will verify in JLCPCB's parts library once schematic is in KiCad.)

---

## Open questions

- [ ] Should the USB-C connector be 16-pin (with all sideband) or 6-pin
      (just power + data, smaller)? For this design, 16-pin is
      cleaner (no need for separate 5.1k pull-downs on the CC lines
      externally), but takes more PCB space.
- [ ] Reverse polarity protection on the 12V input: TVS only, or
      TVS + P-MOSFET ideal-diode? The TVS handles transients; a
      P-MOSFET ideal-diode handles sustained reverse. For a
      battery-powered device where reverse polarity is unlikely
      (battery has fixed polarity), TVS is enough. Skipping the
      P-MOSFET for v3.
- [ ] Should we add an SD card slot for data logging? The firmware
      has MQTT log streaming but no on-board logging. Out of scope
      for v3.
- [ ] Battery management: the BMS is in the battery, not on the PCB.
      PCB only has the fuse + TVS.

---

## Implementation order (todo)

See the master todo list — this doc is the schematic spec / source of
truth, but the actual capture happens in KiCad once the install
finishes.

1. Wait for KiCad 10.0 install
2. Open KiCad, create new project `wattplot-v3.kicad_pro` under
   `hardware/pcb-v3/`
3. Capture schematic sheet 1: Power tree (12V input → 5V → 3.3V)
4. Capture schematic sheet 2: ESP32-S3 module + USB-C + boot logic
5. Capture schematic sheet 3: 2× DRV8871 H-bridges
6. Capture schematic sheet 4: 2× INA219 + I²C bus
7. Capture schematic sheet 5: Sensor interfaces (1-Wire, soil moisture)
8. Capture schematic sheet 6: Connectors + test points
9. Annotate, ERC, generate netlist
10. Place components on PCB
11. Route power (12V, 5V, 3.3V) with wide traces
12. Route signal
13. Pour ground plane
14. DRC
15. Generate Gerbers, BOM, CPL
16. Upload to JLCPCB

---

## Changelog

- 2026-08-08: Initial spec. Maps v1 block diagram + current firmware
  v3.2 onto a single board. 80×60mm 2-layer, JLCPCB SMT.

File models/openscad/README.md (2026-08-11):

# models/openscad -- OpenSCAD model of the Wattplot

The canonical parametric 3D model of the Wattplot planter, written
in [OpenSCAD](https://openscad.org/). Pairs with the FreeCAD
Python model under `models/freecad/`; the FreeCAD version is
authoritative, the OpenSCAD version is a teaching reference
implementation that doesn't require a GUI to render.

## Files

| File | Purpose |
|---|---|
| `wattplot.scad` | The full assembly. Renders the bed, posts, frame, panel, hinges, and actuator at the LONGi Hi-MO X10 620W preset, 35° panel tilt. ~150 lines (most of the geometry is in `parts/`). |
| `wattplot_params.scad` | A hand-maintained mirror of `wattplot_params.py` at the repo root. All dimensions in inches. The CI test `firmware/tests/test_openscad_params.py` verifies Python/SCAD parity so they don't drift. |
| `technical_drawing.scad` | Renders the same assembly as a 2D orthographic projection for the docs site's engineering section. Camera angle is set at render time (top / side / front). |
| `parts/` | Per-part modules. Each `.scad` in this directory is a self-contained part (bed, posts, hinges, panel, frame, actuator) that includes the params file and can be opened directly to render just that part. `wattplot.scad` is now a thin orchestrator that `use <>`s them. |
| `parts/_palette.scad` | Shared color palette (the canonical wattplot.scad defines its own palette inline; the per-part files each define defaults so they can render standalone). |
| `presets/` | Reserved for per-preset `.scad` files (not yet generated). The Makefile and `tools/render_openscad.sh` already render the canonical model with per-preset `-D` overrides. |

## Render

You need OpenSCAD 2021.01 or newer. Install with:
- macOS: `brew install openscad`
- Debian/Ubuntu: `apt install openscad`
- Windows: `choco install openscad`

Then either:

```bash
# one-liner (LONGi 620W only)
openscad -o wattplot.stl models/openscad/wattplot.scad

# all 5 panel presets (longi_620W, residential_60cell,
# residential_72cell, commercial_96cell, large_format_1m65)
make scad-stl-all

# preview PNGs for the docs site (camera angle set for the gallery)
make scad-preview

# 2D technical drawings (top, side, front orthographic projections)
make scad-tech-drawings

# render a single part standalone
openscad -o bed.stl models/openscad/parts/bed.scad
openscad -o frame.stl models/openscad/parts/frame.scad
```

The Makefile lives at the repo root. The shell-script wrapper is
`tools/render_openscad.sh`. Both keep the per-preset dimension
table in sync with `wattplot_params.py`'s `PANEL_PRESETS`.

## Changing a parameter

1. Edit `wattplot_params.py` first (the Python source of truth).
2. Edit `models/openscad/wattplot_params.scad` to match, with a
   comment that points at the Python location.
3. Run `pytest firmware/tests/test_openscad_params.py` to verify
   the test still passes.
4. Re-render the STLs.

If you change a value in the SCAD file first, the test will fail
and tell you which Python value is out of sync. Don't fight the
test -- fix the drift on the Python side.

## Coordinate system

- `X` = bed length (south → north). The hinge axis runs along X.
- `Y` = up.
- `Z` = bed width (east → west).

The hinge axis is at `Y = bed_rim_h_in + 0.5"` (top of the south
wall + a ½" hinge offset), `Z = -bed_outer_W_in/2 + 0.5"`. The
panel tilts around the X axis through this point.

## Show / hide flags

Each major component is gated by a `show_*` boolean at the top
of `wattplot.scad`:

```openscad
show_soil     = true;   // soil fill (visual placeholder)
show_bed      = true;   // walls + cleats + headers + skids
show_posts    = true;   // 4x4 corner posts + 2x6 panel rails
show_frame    = true;   // 2x6 perimeter + 2x4 diagonal brace
show_panel    = true;   // the panel
show_actuator = true;   // linear actuator + clevis blocks
show_hinges   = true;   // 4 butt hinges + steel rod
show_clamps   = true;   // 6 aluminum mid-clamps
show_grid     = false;  // 1' grid for scale (off by default)
```

Pass `-D show_soil=false` etc. to suppress a component. Useful
for technical drawings: `openscad -D 'show_soil=false' -D
'show_actuator=false' -o frame_only.stl models/openscad/wattplot.scad`.

## What's deliberately NOT in the model

- **Soil texture / roots** -- the soil fill is a single cube.
  Real soil is 4,000 lb of damp loam; modeling it as anything
  more than a placeholder would just inflate the STL.
- **Microinverter / MPPT** -- the model is mechanical, not
  electrical. The ESP32, INA219s, and DRV8871s are not in scope.
- **Fasteners** -- screws, bolts, and panel clamps are present
  but only as solid blocks. Real fasteners would need
  parametric threads.
- **The 5 panel presets** -- the canonical model uses the LONGi
  620W (the default). The Makefile and shell wrapper render the
  other 4 via `-D` overrides. Per-preset `.scad` files in
  `presets/` are a future commit; they're not strictly necessary
  because the `-D` overrides are deterministic.

## CI

`firmware/tests/test_openscad_params.py` is the source-of-truth
drift detector. It runs as part of the firmware pytest job (137+
tests) and as a `docs/` job step in `.github/workflows/test.yml`
(if we add one for the docs site). The test fails with a specific
diff on any Python/SCAD drift.

## What to render first

If you're reading this for the first time:

```bash
make scad                          # ~30s, $fn=16, ~500 KB
make scad-stl                      # ~2 min, $fn=64, ~2 MB
make scad-stl-all                  # all 5 presets, ~10 min
make scad-preview                  # 5 PNGs for the docs site
```

Open the PNGs in `renders/` to see the booth preview. The STL
files can be sliced with PrusaSlicer or any standard FDM
slicer. The Mini v2.4 build fits on a 250×210 mm bed; the
full-size is too big for FDM and is intended as a visualization
+ collision-check tool, not a print.

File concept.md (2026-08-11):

# Wattplot - Concept Brief

**One bed. Two harvests.**

A DIY, open-source 4×8 ft planter whose canopy is a working solar panel.
The same square foot grows tomatoes *and* generates electricity — not
because the panel was designed for the bed, but because the bed and the
panel need the same thing: a frame, an angle, and a reason to be in
the sun. **Symbiosis of energy production and agriculture.**

## Problem

Backyard, patio, and small-farm growers want to:
- Grow food in a controlled, raised bed
- Add solar generation without sacrificing growing space
- Avoid the cost and complexity of commercial agrivoltaic systems

Standard solutions force a trade-off: solar panel OR garden bed, not both.

## Core Idea

A 4×8 ft raised planter where:
- The **canopy is a working solar panel** — same orientation, same hardware, same grid tie as a rooftop install
- The **bed below grows tomatoes** (and compatible companions) in soil
- The **symbiosis** is engineered: filtered afternoon shade where the crop needs it most, less evaporation, rain diversion to roots, and electricity that offsets the pump, irrigation, solenoid, and any grid load — all from the same structure

The panel isn't a roof over a garden. The garden isn't a basement under
a solar array. They're the same object.

## Target User

- DIY maker / homesteader
- Smallholder farmer
- School / community garden
- Off-grid or resilience-minded household

Skill level: comfortable with basic carpentry and wiring. No specialized tools beyond a drill, saw, multimeter.

## Constraints (from the brief)

- 4 ft x 8 ft footprint
- Common / off-the-shelf materials
- Open-source (publishable drawings, BOM, code)
- Tomato as the primary crop

## Key Design Questions to Resolve

- Canopy tilt angle vs. sun-tracking vs. fixed
- Glazing: rigid panels, semi-transparent laminate, or bifacial modules with spacing
- Mounting height for crop clearance and airflow
- Water: rain capture into the bed, drip irrigation, soil-moisture sensing
- Electrical: grid-tie vs. off-grid battery vs. direct-load (pump, fan)
- Tomato variety: determinate bush vs. indeterminate vine (affects canopy height)
- Structural: wood frame, aluminum extrusion, or steel
- Thermal: does the canopy cook the bed? Ventilation gap?

## Out of Scope (initial version)

- Greenhouse automation
- Commercial-scale deployment
- Crops other than tomatoes (v1)
- Permitting / utility interconnection paperwork (v1)

## Success Looks Like

- One weekend build with under ~$500 in materials
- Produces 400-800 kWh/yr (estimate, to validate)
- 20-50 lb tomato harvest per season (estimate, to validate)
- Public repo with BOM, cut list, wiring diagram, firmware, planting guide

## Open Questions

- Is the canopy also the rainwater catchment, or separate?
- Battery or no battery in v1?
- Single-axis tracker or fixed for v1?
- Companion plants (basil, marigold) integrated or separate?

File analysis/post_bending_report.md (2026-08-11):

# Wattplot v2 — Post Bending & Lateral Bracing Analysis

**Companion to `analysis/wind_load_report.md`.** That report treats the structure as a rigid body tipping about the bed edge; this one checks whether the 4x4 posts themselves survive the same wind as cantilevers, and what it takes to brace them so their base connections don't have to resist a bending moment.

**Post:** 4x4 PT Douglas Fir (Pressure Treated), 3.5" × 3.5" actual, 72" tall, 4 posts total.
**Allowable stresses (NDS wet-use × CD 1.6 wind duration):** Fb' = 1400 psi, Fv' = 288 psi. No other NDS adjustment factors (size, beam-stability) applied — first-pass, not a stamped calc.
**Load-sharing assumption:** worst-case, 2 of 4 posts carry the full panel drag between them (no credit taken for the other 2 posts or for rail-frame stiffness). This is the conservative case for an UNBRACED frame — see §Bracing below for how bracing changes this.

## Bending, shear, and deflection at the post base

| Tilt | V_base (lb) | M_base (ft·lb) | f_b (psi) | SF bending | f_v (psi) | SF shear | defl (in) | SF defl | |
|---|---|---|---|---|---|---|---|---|---|
| 0° | 56 | 167 | 280 | 4.99 | 7 | 42.27 | 0.15 | 2.70 | ✅ |
| 15° | 93 | 393 | 660 | 2.12 | 11 | 25.41 | 0.43 | 0.94 | ⚠️ |
| 25° | 154 | 770 | 1293 | 1.08 | 19 | 15.26 | 0.89 | 0.45 | ⚠️ |
| 35° | 237 | 1278 | 2145 | 0.65 | 29 | 9.93 | 1.52 | 0.26 | ⚠️ |
| 45° | 331 | 1855 | 3115 | 0.45 | 41 | 7.10 | 2.23 | 0.18 | 🚫 above cap |
| 50° | 379 | 2148 | 3607 | 0.39 | 46 | 6.20 | 2.59 | 0.15 | 🚫 above cap |
| 75° | 570 | 3317 | 5570 | 0.25 | 70 | 4.13 | 4.04 | 0.10 | 🚫 above cap |
| 90° | 607 | 3543 | 5949 | 0.24 | 74 | 3.88 | 4.32 | 0.09 | 🚫 above cap |

## Verdict at the 35° operating cap

**This check FAILS at the 35° operating cap, unbraced.** The overturning check in `wind_load_report.md` passing does not mean the posts survive — they're a separate failure mode, and this one governs first.

- Bending: **2145 psi** vs. Fb' = 1400 psi → SF **0.65** (target ≥ 1.5) — **FAIL**
- Shear: **29 psi** vs. Fv' = 288 psi → SF **9.93** (target ≥ 1.5) — PASS
- Deflection: **1.52"** vs. limit 0.40" (L/180) → SF **0.26** — **FAIL**
- **Base connection demand: M = 1278 ft·lb, V = 237 lb.** Most off-the-shelf post-base brackets (e.g. Simpson Strong-Tie ABU/CBSQ) are pin connections rated for shear + uplift, **not** a bending moment this size — so even if the wood section itself were beefed up, the connection is a second gap.

**Bending, not shear or deflection, is the governing failure.** Shear passes with SF ≈ 10 even at 35°, and deflection is a serviceability concern, not a strength one. The 4x4 section is simply too small in bending for a 6-ft cantilever under this load, under the conservative (2-of-4-posts) load-sharing assumption.

**Unbraced tilt limits, bending alone:** SF drops below the 1.5 target at **20°** and below 1.0 (stress exceeds allowable) at **26°**. Bending fails well before the 35° overturning-derived cap — the real operating limit for an unbraced 4x4 post is closer to 20° than 35°.

**Sensitivity — optimistic 4-post-uniform sharing** (crediting all 4 posts equally instead of the conservative 2 used above): M drops to 639 ft·lb, stress to 1073 psi, SF to **1.31** — still below the 1.5 target. Even the optimistic case does not pass without bracing or a bigger post.

## Two remedies (either closes the gap; pick one)

**Option A — upsize to 6x6 posts.** At 35° with the same conservative 2-post sharing: S = 27.7 in³ (vs. 7.1 in³ for 4x4), stress = 553 psi, **SF = 2.53 — PASS** with margin. Simplest fix; no bracing design needed. Cost: heavier/pricier posts (6x6 PT DF vs 4x4) and the frame/hardware already sized around 4x4 rail pockets would need rechecking.

**Option B — lateral bracing (square-cut, per design rule #1).** A 45° knee brace from post to rail near the post top converts the post-and-rail portal frame from a **moment frame** (base resists bending) to a **braced frame** (base resists shear + axial only; the brace carries the racking force axially). The obvious brace geometry needs mitered ends — the escape hatch is a **square-cut gusset plate**: a short square-cut timber brace (or a plywood/steel gusset alone) bolted flat across the post/rail corner, carrying the same axial force a mitered brace would without a single non-90° cut. At the 35° cap (45° brace, 18" legs): brace axial force = **335 lb**, spec target ≥ 503 lb — well within off-the-shelf structural angle brackets (design rule #2).

**Bracing alone does not fully retire the base-moment problem** — it reduces the effective cantilever to the short run below the brace's lower attachment point, it doesn't zero it out. Model that residual moment once a specific bracket height is chosen, and confirm it's within a standard post-base bracket's rating before treating Option B as sufficient on its own. Option A (upsize) is the more conservative and simpler fix if the frame geometry can absorb a larger post; Option B is lighter/cheaper if the residual moment checks out.

## Notes & caveats

- **First-pass engineering, not stamped calcs.** Same caveat as `wind_load_report.md`. A real build should get a PE stamp before the full-size Smart tier goes in the ground.
- **Load sharing among the 4 posts is the biggest modeling assumption here.** This analysis conservatively assumes only 2 posts share the load (matching wind_load.py's existing '2 effective posts' convention for post self-drag) because, absent a bracing design, there's no rigid mechanism guaranteeing the other 2 posts help. Once bracing (above) is actually built, the true per-post demand is lower than this table shows — but the table's numbers are the ones that should size the base connection if you're not ready to trust the bracing.
- No NDS size factor (CF) or beam-stability factor (CL) applied to the allowable bending stress — only the load-duration factor CD. Both would typically increase the allowable slightly for a post this size, so this is conservative, not unconservative.
- Deflection limit (L/180) is a judgment call for a canopy, not a code-mandated value the way it might be for a roof diaphragm. Treat the deflection numbers as a serviceability sanity check, not a pass/fail structural limit.
- Panel drag is assumed delivered to the post tops as a point load at the panel centroid height — consistent with `wind_load.py`'s own overturning-moment model, but a real rail-to-post connection distributes some of that load below the very top.

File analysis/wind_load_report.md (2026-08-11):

# Wattplot v2 — Wind Load Analysis

**Site:** Phoenix, AZ (Maricopa County)  
**Standard:** ASCE 7-22, Risk Cat II, 700-yr MRI  
**Basic wind speed V:** 115.0 mph 3-sec gust (51.4 m/s) at 33 ft, Exposure C  
**Exposure:** C (Kzt = 1.0, Kd = 0.85)  
**Force coefficient Cf:** 1.5 (open tilted plate, conservative)

## Geometry

- **Canopy on 72" corner posts** — panel centroid at 6.1 ft above grade. This long lever arm, not uplift, is what governs the design.
- **Operating tilt capped at 35°** (`CONTROL['max_tilt_deg']`). Rows above it below are shown to document why the cap exists — they are NOT operating states.
- Panel: 8.083333333333334 ft × 3.716666666666667 ft × 1.4" (30.04 sq ft, ~65.0 lb); tilts about its long axis, so the 3.72 ft width rises
- Bed: 8.0 ft × 3.716666666666667 ft × 27.5" wall, 25.5" soil fill
- Corner-post drag included: 2 effective posts × Cf 1.3 acting at 3.0 ft
- Wood density assumed: 30.0 pcf (PT pine, conservative)
- Soil density assumed: 75.0 pcf (wet loam/compost, ×1.0 saturation)
- Bed-on-grade friction: μ = 0.4

## Dead load (ballast) at 25.5" soil depth

| Component | Weight |
|---|---|
| Soil (60.10 cu ft) | 4508 lb |
| Lumber (posts + beam + walls) | 222 lb |
| Panel | 65 lb |
| Hardware (hinges/bolts) | 25 lb |
| **Total dead load W** | **4820 lb** |

## Force sweep across tilt angles

| Tilt | qh (psf) | F_vert (uplift, lb) | F_horiz (drag, lb) | SF uplift | SF sliding | SF overturning | |
|---|---|---|---|---|---|---|---|
| 0° | 24.5 | 0 | 111 | n/a | 17.32 | 26.83 | ✅ |
| 15° | 24.5 | 276 | 185 | 17.49 | 10.41 | 6.90 | ✅ |
| 25° | 24.5 | 422 | 308 | 11.42 | 6.26 | 3.85 | ✅ |
| 35° | 24.5 | 518 | 474 | 9.31 | 4.07 | 2.55 | ✅ |
| 45° | 24.5 | 551 | 662 | 8.75 | 2.91 | 1.89 | 🚫 above cap |
| 50° | 24.5 | 543 | 758 | 8.88 | 2.54 | 1.69 | 🚫 above cap |
| 75° | 24.5 | 276 | 1140 | 17.49 | 1.69 | 1.25 | 🚫 above cap |
| 90° | 24.5 | 0 | 1214 | n/a | 1.59 | 1.26 | 🚫 above cap |

Drag column includes corner-post drag (111 lb, constant with tilt).

## Verdict at the 35° operating cap (25.5" soil depth)

At the max operating tilt of 35° (and V = 115.0 mph):

- Uplift safety factor: **9.31** (target ≥ 1.5) — PASS
- Sliding safety factor: **4.07** (target ≥ 1.5) — PASS
- Overturning safety factor: **2.55** (target ≥ 2.0) — PASS

**Rated deployed wind speed at 35°: ~130 mph** (the speed at which the governing safety factor reaches its target).

Stowed flat (0°) the panel contributes no drag or uplift and only the posts are loaded — SF overturning 26.8. **Stowing is the storm answer for both tiers.**

## Recommended soil depth

Required soil depth is solved at the 35° operating cap (above the cap is not an operating state).
To hit the overturning target SF ≥ 2.0 at 35° tilt and V = 115.0 mph, you need approximately:

### **Soil depth ≥ 19.6"** (1.64 ft)

The build ships 25.5" (27.5" wall = 5 courses of 1x6, 2" freeboard). At the required depth:

- Total dead load: 3786 lb
- SF uplift: 7.31, SF sliding: 3.20, SF overturning: 2.00

## Notes & caveats

- **First-pass engineering, not stamped calcs.** If this is a real build in Phoenix city limits, the structure may need a permit and a PE stamp. Maricopa County wind amendments and IRC triggers are real.
- Cf = 1.5 is conservative for an open plate. ASCE 7 doesn't have a dedicated section for a one-panel solar canopy, so we used a free-plate value. A real calc could refine with wind-tunnel data or a CFD check.
- **Soil weight is the swing variable, and it cuts against us.** We assume 75.0 pcf (wet loam). Dry desert soil can be 55-65 pcf, which drops SF overturning at 35° to ~1.9-2.2. This is exactly why the bed is 27.5" (5 courses) and not 4 courses — at 4 courses a dry bed falls to SF 1.53, below target. Keep the bed watered, or treat a bone-dry bed as a reason to stow.
- Friction coefficient μ = 0.4 is a conservative estimate for PT pine on dirt. Wet/muddy ground could be 0.2-0.3; on a gravel pad or concrete, could be 0.5-0.6.
- **Post drag is modeled crudely.** 2 of 4 posts at Cf 1.3, assuming the leeward pair is fully shielded. ASCE 7-22 Ch. 29 open-frame provisions would be the rigorous route.
- **The posts themselves are checked separately, in `analysis/post_bending.py` / `post_bending_report.md`.** This analysis treats the structure as a rigid body tipping about the bed edge; it does not model the 4x4 posts as cantilevers carrying panel drag at their base connection. That check exists now — and it **fails** the 4x4 posts, unbraced, at the 35° operating cap. See the companion report for the two remedies (upsize to 6x6, or square-cut lateral bracing).
- The big lever here is **soil depth**. Every extra inch of soil is ~190 lbof ballast. If you want a margin, go deeper rather than wider.

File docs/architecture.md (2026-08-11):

# Wattplot — Software Architecture

This document maps the runtime components, the data they exchange,
and the trust boundaries. The hardware architecture lives in
[`docs/pinmap.html`](pinmap.html) and
[`docs/schematic.html`](schematic.html); this document is the
software side.

```
┌────────────────────────────────────────────────────────────────────────┐
│  github.io (static site)                                              │
│  https://wattplot.org/                                  │
│  - HTML, CSS, three.js 3D viewer, dashboard, gallery                   │
│  - Reads live data via CORS to control.wattplot.org                  │
└────────────────────────────────┬───────────────────────────────────────┘
                                 │ HTTPS (CORS allowlist: github.io)
                                 │ GET /api/state, /api/whoami, /api/logs
                                 ▼
┌────────────────────────────────────────────────────────────────────────┐
│  Cloudflare edge (control.wattplot.org)                             │
│  - TLS termination, DDoS                                              │
│  - Access policy on POSTs: email OTP → mokahlou@gmail.com only        │
│  - Path Bypass list: GET /api/state, /api/logs, /api/whoami           │
│    (public, no auth)                                                  │
└────────────────────────────────┬───────────────────────────────────────┘
                                 │ tunneled (cloudflared service)
                                 │ localhost:8765 (HTTP, plain)
                                 ▼
┌────────────────────────────────────────────────────────────────────────┐
│  tools/wattplot_control.py  (operator's PC, Windows)                  │
│  - aiohttp server on 127.0.0.1:8765                                   │
│  - zeroconf discovery → wattplot-controller.local:6053                │
│  - ReconnectLogic + 30 s link watchdog                                │
│  - Translates /api/{switch,number,select,button} → ESPHome commands    │
│  - Logs to rotating wattplot.log (when MQTT broker is up)             │
└────────────────────────────────┬───────────────────────────────────────┘
                                 │ Noise PSK (encrypted ESPHome native API)
                                 │ ESPHome native protocol over TCP:6053
                                 ▼
┌────────────────────────────────────────────────────────────────────────┐
│  ESP32-S3-DevKitC-1-N16R8  (the wattplot-controller device)            │
│  firmware/wattplot.yaml (2029 lines)                                  │
│  - 1 Hz control loop (state machine + PI)                             │
│  - 100 ms endpoint_detector (current-spike endstops)                  │
│  - 1 s energy integration (INA219 V × I → kWh)                        │
│  - 60 s grow_light_tick (auto-watering policy)                        │
│  - 5 s alive_tick (DEBUG ping)                                        │
│  - 15 min NWS poll (forecast globals)                                 │
│  - 5 min DLI update                                                    │
│  - MQTT → wattplot/log topic (when broker configured)                  │
└────────────────────────────────┬───────────────────────────────────────┘
                                 │ DC bus, I²C, 1-Wire, GPIO, IPROPI
                                 ▼
┌────────────────────────────────────────────────────────────────────────┐
│  Hardware (schematic rev B, 2026-08-03)                                │
│  - 620 W LONGi Hi-MO X10 bifacial panel (or Mini's 10 W ECO-WORTHY)   │
│  - DRV8871 U5a (actuator) on GPIO1/2/11                               │
│  - DRV8871 U5b (solenoid) on GPIO10/12                                 │
│  - INA219 at 0x40 (motor), INA219 at 0x41 (panel)                       │
│  - 3× DS18B20 on GPIO16 (1-Wire)                                       │
│  - Capacitive soil moisture on GPIO6                                  │
│  - Battery V divider (100k / 10k) on GPIO7                            │
│  - Actuator IPROPI on GPIO4, solenoid IPROPI on GPIO5                   │
│  - Status LED on GPIO17 (LEDC PWM)                                     │
│  - Sunapex 10A MPPT (standalone, IP67) → 12V LiFePO4                   │
│  - Same panel + Y-splitter → Enphase IQ7+ microinverter                 │
└────────────────────────────────────────────────────────────────────────┘
```

## Data flow (one tick, ~1 s)

1. **ESPHome firmware (on the chip):**
   - ADC reads (10 Hz, internal): motor IPROPI, solenoid IPROPI,
     battery V, soil moisture. The IPROPI sensors are `internal: true`
     so they aren't published to MQTT / HA — they exist only for
     the `endpoint_detector` script.
   - Public sensors (1-2 s, named): Panel V, Panel Current, Panel
     Power, Battery Voltage, Battery SOC, Soil Moisture, Soil
     Temperature, Panel Temperature, Canopy Air Temperature,
     POA Irradiance, Panel Efficiency, Energy Today, Energy Total.
   - `control_loop` runs every 1 s. Reads `panel_tilt`, `i_motor`,
     `i_safe_limit`, `at_zero`, `at_max`. Applies PI to adjust
     commanded tilt.
2. **Push:**
   - The ESPHome native API pushes the full state vector over the
     Noise-PSK-encrypted TCP connection (port 6053).
3. **Server (`wattplot_control.py`):**
   - `aioesphomeapi` callback updates the in-memory state.
   - `_last_push` timestamp recorded; the watchdog compares against
     `STALE_FORCE_RECONNECT_S = 30.0`.
   - On `/api/state` request: serialize the state to JSON with a
     `_meta` block (`connected`, `stale_for_s`, `last_update_epoch`,
     `stale`).
4. **Panel (`docs/control.html`):**
   - Polls `/api/state` every 2 s.
   - Renders each sensor; shows the stale-data banner if
     `_meta.stale`.
   - On control click: `POST /api/{switch,number,select,button}`.
5. **Cloudflare Access:**
   - Intercepts the POST. If no `CF_Authorization` cookie, runs
     the email-OTP flow.
   - Authorized requests are forwarded to `wattplot_control.py`.
6. **Server writes back:**
   - Maps `{label, value}` to the ESPHome entity by name (labels
     are stable strings, server looks up the key).
   - `aioesphomeapi.{switch,number,select,button}_command(key=...)`.

## Trust boundaries

| Boundary | Trust | Mechanism |
|---|---|---|
| Browser ↔ Cloudflare | Public | TLS, Cloudflare Access (email OTP for POSTs) |
| Cloudflare ↔ `wattplot_control.py` | Same operator | `cloudflared` tunnel, plain HTTP on localhost |
| `wattplot_control.py` ↔ ESPHome chip | Same operator | Noise PSK (encrypted), mDNS discovery |
| ESPHome ↔ Sensors / DRV8871s | Same operator | I²C bus (PCB), 1-Wire pullup, GPIO |
| ESPHome ↔ MPPT | None (decoupled) | Sunapex is standalone; no host connection |
| `bring_your_own_panel.py` ↔ wattplot_params | Operator | Same workstation, plain Python |
| `analysis/*.py` ↔ pvlib TMY data | Public | pvlib ships its own TMY files |

The **only** external attack surface is the Cloudflare edge. The
ESPHome Noise PSK on the LAN is an opaque string but anyone on the
local network who learns it can drive the actuator — see
[`CONTRIBUTING.md`](../CONTRIBUTING.md) § Security for the rotation
posture.

## Component lifetimes (what runs where)

| Process | Where | Always on? | Notes |
|---|---|---|---|
| `firmware/wattplot.yaml` (compiled to C++) | ESP32-S3 | Yes | Boots into `Folding` (safe default). |
| `tools/wattplot_control.py` | Operator's PC | Booth: yes. Bench: on demand. | Background service via Task Scheduler (Windows) or systemd (Linux). |
| `tools/log_subscriber.py` | Operator's PC | Booth: yes. Bench: optional. | Only meaningful when Mosquitto is running. |
| `cloudflared` (Cloudflare Tunnel) | Operator's PC | Booth: yes. Bench: optional. | Runs as a Windows service. |
| `jekyll serve` (local dev preview) | Operator's PC | No | Only when iterating on `docs/`. |
| GitHub Actions | GitHub infra | No | PR + push only. |

## What is *not* in this architecture (yet)

- **No MQTT broker in CI.** The CI runs pytest on `firmware/tests/`
  and the analysis scripts; it doesn't need a live chip or a broker.
- **No Jetson / edge compute.** The ESPHome firmware runs on the
  chip; the server is the thin proxy in front. Adding a local
  ML/data pipeline (e.g., for DLI prediction) would be a new layer.
- **No HA addon.** Home Assistant is downstream of the ESPHome
  integration; we don't ship a custom component.
- **No OTA signing server.** OTA password is sufficient for the
  booth's threat model.

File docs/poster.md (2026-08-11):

# Wattplot, Poster Concept (24×36 vertical)

> **STALE — references the retired `BedSun` (90°) "sun" mode and the
> BMI160 IMU. Both are gone in v3.2.** Update the mode list before
> printing; the rest of the framing is fine. See `firmware/README.md`
> for current behavior.

> This is the **text and layout** for the booth poster. Send to a
> designer (Fiverr, local student) for visual execution. Print at
> FedEx Kinko's on foam core, ~$40.

## Headline (optimization lead, upcycling as a benefit)

One bed. Two harvests. The panel canopy is what the frame would
have been lumber for anyway, so the bed is doing more work, not
the panel displacing the garden. (Upcycling angle: ~10M tons of
panel waste by 2050. A Wattplot gives any decommissioned panel a
job — shade + food + some power, in a planter you build from
8-ft lumber stock. Bring your own panel, 8×5 ft fits any
residential.)

## Layout

```
┌────────────────────────── 24" ──────────────────────────┐
│  ┌──────────────────────────────────────────────────┐   │
│  │  WATTPLOT                                          │   │
│  │  One bed. Two harvests.                            │   │
│  │  Shade + food + power, in one raised bed.          │   │
│  └──────────────────────────────────────────────────┘   │
│                                                            │
│  ┌──────────────────────────┐  ┌────────────────────┐    │
│  │                          │  │  WHAT IT IS        │    │
│  │  [ LARGE RENDER:         │  │                    │    │
│  │    iso view of full-size │  │  Up to 8 ft × 5 ft │    │
│  │    with old salvage      │  │  raised bed with   │    │
│  │    panel, tomato plants, │  │  a hinged solar    │    │
│  │    full sun ]            │  │  canopy.           │    │
│  │                          │  │                    │    │
│  │  Use: wattplot_v2_iso.png│  │  Fits any panel    │    │
│  │                          │  │  up to 97"×61".    │    │
│  │  Caption: "Old 250W      │  │  Bring your own.   │    │
│  │   panel, 12 years        │  │                    │    │
│  │   retired from a         │  │  5 panel presets:  │    │
│  │   rooftop. Now grows     │  │  60-cell, 72-cell, │    │
│  │   tomatoes in Phoenix."  │  │  96-cell, 1m65,    │    │
│  │                          │  │  new bifacial.     │    │
│  └──────────────────────────┘  └────────────────────┘    │
│                                                            │
│  ┌────────────────────────────────────────────────────┐  │
│  │  HOW IT WORKS (one-line summary)                  │  │
│  │  sun → panel → MPPT → battery + microinverter     │  │
│  │  controller: rain / wind / soil / sun → tilt       │  │
│  └────────────────────────────────────────────────────┘  │
│                                                            │
│  ┌──────────────────┐  ┌──────────────────┐  ┌────────┐  │
│  │  [ render:       │  │  [ render:       │  │  $193  │  │
│  │    flat (storm)  │  │    35° (power)   │  │  mini  │  │
│  │    at 0° ]       │  │    at 35° ]      │  │  on    │  │
│  │                  │  │                  │  │  the   │  │
│  │  STORM FOLD      │  │  POWER MODE      │  │  table │  │
│  │  high wind       │  │  tilt for max    │  │        │  │
│  │  → flat          │  │  annual kWh      │  │  $1400 │  │
│  │                  │  │                  │  │  full- │  │
│  │  wattplot_v2_    │  │  wattplot_v2_    │  │  size  │  │
│  │  flat_iso.png    │  │  iso.png         │  │        │  │
│  └──────────────────┘  └──────────────────┘  └────────┘  │
│                                                            │
│  ┌────────────────────────────────────────────────────┐  │
│  │  WHY UPCYCLE?                                     │  │
│  │  ~10M tons of panel waste by 2050 (IRENA).         │  │
│  │  Most panels are removed because the racking       │  │
│  │  or inverter failed, not the cells.                │  │
│  │  A 12-year-old 250W panel is still 235W.           │  │
│  │  Wattplot gives that panel a job: shade + food     │  │
│  │  + some power, delaying recycling 10-20 years and  │  │
│  │  recovering 50-90% of the original.                │  │
│  └────────────────────────────────────────────────────┘  │
│                                                            │
│  ┌────────────────────────────────────────────────────┐  │
│  │  THE SMART CONTROLLER (decision stack)            │  │
│  │  1. user override  2. safety  3. NWS rain         │  │
│  │  4. NWS wind  5. soil wet  6. soil dry           │  │
│  │  7. time-of-day  8. mode (power / sun / track)   │  │
│  └────────────────────────────────────────────────────┘  │
│                                                            │
│  ┌──────────────────┐  ┌──────────────────────────────┐  │
│  │  GITHUB          │  │  OPEN SOURCE · MIT ·         │  │
│  │  [QR code →      │  │  parametric · code-first     │  │
│  │  repo]           │  │  5 panel presets ·           │  │
│  │                  │  │  sun sim · wind sim · IMU    │  │
│  │                  │  │                              │  │
│  │                  │  │  github.com/mokahlo/wattplot │  │
│  └──────────────────┘  └──────────────────────────────┘  │
│                                                            │
└────────────────────── 36" ───────────────────────────────┘
```

## Color & type

- **Background:** off-white (#F8F4E9) or matte black (#1A1A1A).
  Off-white reads better in daylight. Matte black pops under spotlights.
- **Title font:** 96pt, sans-serif bold, dark.
- **Body font:** 24-32pt, sans-serif regular.
- **Numbers ($193, 2,240 kWh, 84 kg):** 64pt, bold, accent color.
- **QR code:** 4"×4" minimum, high-contrast, in the bottom corner.

## Source files

- **Renders used:** `renders/wattplot_v2_iso.png`, `renders/wattplot_v2_flat_iso.png`,
  `renders/wattplot_v2_east.png`, `renders/wattplot_v2_top.png`,
  `renders/sun_simulator_monthly_dli.png` (if you want a data viz),
  `renders/wind_load_forces.png` (optional).
- **QR code:** generate from the GitHub repo URL using
  <https://www.qrcode-monkey.com/>. 4-color (black on white) is fine.

## Designer hand-off

Send this `POSTER.md` plus the renders to a designer. Ask for:
- 24"×36" vertical, 300 DPI print-ready PDF
- Editable source (Figma, Illustrator, or InDesign)
- Two rounds of revision

**Budget:** $100-200 on Fiverr for a clean technical poster. Or
ask a local design student; this is a portfolio piece for them.

## Print

- **FedEx Kinko's:** 24×36 poster, $20-40 depending on paper
  (matte vs. glossy). Mount on foam core, +$10.
- **Vistaprint:** Same size, similar price, longer lead time.
- **Local print shop:** Often the cheapest, ask.

Order 2-3 weeks before the faire.

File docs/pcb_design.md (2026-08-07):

# Wattplot Controller v1 — PCB Design Specification

> **STALE — written for the v1 PCB (ESP32-WROOM-32E, BMI160 IMU, WS2812B
> status LED, DPS5005 MPPT path, GPIO4/16/17/18/19/21/22/25/32/33/34/35
> pinout, K1 relay for the grow light, J7/J8/J9/J10 connector map).**
> The current hardware is **schematic rev B (2026-08-03)** on
> **ESP32-S3-DevKitC-1-N16R8**, with the IMU / WS2812B / relay / limit
> switches / DPS5005 removed. The block diagram and high-level design
> notes are still useful, but the BOM, netlist, and pin map need to be
> regenerated. See:
>
> - Pin map: `docs/pinmap.html`
> - Schematic: `docs/schematic.html` (rev B, 2026-08-03)
> - Firmware config: `firmware/wattplot.yaml`
> - Firmware quick-start: `firmware/README.md`
>
> A future pass will regenerate this doc against the current schematic.
> Tracked in [ROADMAP.md](../ROADMAP.md).

The custom PCB for the Wattplot v2 smart-folding controller. This document is
the complete specification: schematic, netlist, BOM, board layout, and
assembly notes. Hand it to KiCad / EasyEDA / JLCPCB's free DFM service to
produce the actual board.

**Source of truth:** `firmware/wattplot.yaml` defines the pin map. The PCB
matches it 1:1.

---

## 1. Block diagram

```
                              ┌──────────────────────────────────────┐
                              │  Wattplot Controller v1 (50×70 mm)  │
                              │                                      │
   12V LiFePO4  ──────────────►│ J1 (XT60) ──► 12V rail            │
                              │                  │                  │
                              │            ┌─────▼─────┐            │
                              │            │  12V→5V    │  buck      │
                              │            │  (MP1584)  │  switching │
                              │            └─────┬─────┘            │
                              │                  │                  │
                              │            ┌─────▼─────┐            │
                              │            │  5V→3.3V  │  LDO       │
                              │            │  (AMS1117)│            │
                              │            └─────┬─────┘            │
                              │                  │                  │
   ESP32-WROOM-32E ◄─────────┤ 3V3 rail          │                  │
   (USB-C, WiFi/BT ant.)    │                  │                  │
                              │   ┌──────────────┼──────────────┐   │
                              │   │              │              │   │
                              │   ▼              ▼              ▼   │
                              │ GPIO16/17/18   GPIO21/22      GPIO26/27│
                              │   │              │              │   │
                              │ ┌─▼──┐    ┌─────▼─────┐  ┌─────▼─────┐│
                              │ │DRV │    │ I2C bus   │  │  reserved  ││
                              │ │8871│    │ (3V3)     │  │ (DNP on    ││
                              │ │    │    │  BMI160   │  │  mini, used││
                              │ └─┬──┘    │  INA219   │  │  on full-  ││
                              │   │       │  ext hdr  │  │  size MPPT)││
                              │   │       └───────────┘  └───────────┘│
                              │   │                                     │
                              │   ▼                                     │
                              │  Linear actuator (4" stroke)          │
                              │                                      │
   Battery V sense ──────────►│ GPIO33 (10k/10k divider)             │
   Soil moisture ────────────►│ GPIO32 (capacitive, 0-3V)            │
   DS18B20 ──────────────────►│ GPIO4  (4.7k pullup to 3V3)          │
   WS2812B status LED ───────►│ GPIO25                              │
   Limit switch 0° ──────────►│ GPIO34 (external 10k pullup)        │
   Limit switch 90° ─────────►│ GPIO35 (external 10k pullup)        │
   Grow light relay ─────────►│ GPIO19 (low-side switch, 12V)       │
                              │                                      │
                              │ J2 (4-pin) ext I2C + 3V3 + GND        │
                              └──────────────────────────────────────┘
```

> **v2.4 mini build:** GPIO 26/27 and the J4 footprint are **DNP**
> (do-not-populate). The Sunapex 10A MPPT is standalone with no
> host connection. The 26/27 pads and J4 footprint are reserved for
> the full-size v2 build, where a larger MPPT (Victron 100/30 or
> EPEver 4210AN) talks to the ESP32 over VE.Direct / RS-485 for
> telemetry.

---

## 2. Power tree

Three rails, derived from a 12 V LiFePO4 battery:

| Rail | Source | Max current | Used by |
|---|---|---|---|
| **12 V** | J1 (XT60 from battery) | 5 A (fuse) | Grow light relay, Sunapex MPPT (BAT input via fuse), DRV8871 motor supply |
| **5 V** | MP1584EN buck from 12 V | 3 A | (reserved; USB-C 5V also feeds here for programming) |
| **3.3 V** | AMS1117-3.3 LDO from 5 V | 1 A (peak ~800 mA) | ESP32, BMI160, INA219, DS18B20, WS2812B |

**Battery fuse:** 5 A resettable PTC on the 12 V input (DRV8871 is rated 3.6 A
continuous; 5 A gives headroom for stall currents).

**Reverse polarity protection:** P-MOSFET on the 12 V input (e.g., AO3401A).

**Power flow on startup:**
1. Battery → 12 V rail (through fuse + reverse-polarity protection)
2. 12 V → 5 V (MP1584)
3. 5 V → 3.3 V (AMS1117)
4. ESP32 boots from 3.3 V
5. ESPHome starts, queries IMU/INA219 over I2C, reads battery voltage
   via the divider, reads panel V/I via the panel-side INA219
6. State machine boots in `FOLDING` (safe default) per firmware
7. Sunapex (standalone, on the bed wall) charges the battery from the
   panel — independent of the ESP32's state

---

## 3. Component BOM (PCB-level)

| Designator | Part | Package | Source | Qty | ~$ ea |
|---|---|---|---|---|---|
| U1 | ESP32-WROOM-32E (16 MB flash) | module | Mouser / Espressif | 1 | 3.50 |
| U2 | MP1584EN buck regulator (12V→5V, 3A) | SOIC-8 | TI / LCSC | 1 | 0.40 |
| U3 | AMS1117-3.3 LDO (5V→3V3, 1A) | SOT-223 | TI / LCSC | 1 | 0.10 |
| U4 | DRV8871 H-bridge motor driver | WSON-8 | TI / LCSC | 1 | 1.80 |
| U5 | BMI160 IMU (I2C, 0x68) | LGA-14 | Bosch / Mouser | 1 | 2.00 |
| U6 | INA219 current/power sensor (I2C, 0x40) | SOIC-8 | TI / LCSC | 1 | 1.20 |
| U7 | AO3401A P-MOSFET (reverse polarity) | SOT-23 | LCSC | 1 | 0.05 |
| Q1 | BC847 NPN (grow light relay driver) | SOT-23 | LCSC | 1 | 0.02 |
| K1 | SRD-12VDC-SL-C relay (or SSR-25DA, 12V coil) | through-hole | TME / LCSC | 1 | 0.80 |
| F1 | 5 A resettable PTC fuse (Bourns MF-R050) | radial | LCSC | 1 | 0.20 |
| L1 | 22 µH 3A inductor (for MP1584) | SMD 4×4 mm | Coilcraft / LCSC | 1 | 0.30 |
| L2 | 10 µH (for DRV8871 output filter, optional) | SMD | LCSC | 1 | 0.20 |
| C_bulk | 100 µF 25 V aluminum polymer (12 V rail) | SMD 6.3×5.4 mm | Panasonic | 2 | 0.40 |
| C_5V | 22 µF 10 V ceramic (5 V rail) | SMD 0805 | Murata | 2 | 0.10 |
| C_3V3 | 10 µF 10 V ceramic (3.3 V rail) | SMD 0805 | Murata | 2 | 0.10 |
| C_bypass | 100 nF 16 V ceramic (each IC) | SMD 0402 | Murata | 12 | 0.01 |
| D1 | SS34 Schottky (reverse polarity clamp) | SMA | ON Semi | 1 | 0.10 |
| D2 | 1N4148 (flyback for relay) | SOD-123 | ON Semi | 1 | 0.02 |
| LED1 | WS2812B (status) | 5050 | Worldsemi | 1 | 0.40 |
| J1 | XT60 connector (12 V battery) | through-hole | Amass | 1 | 0.80 |
| J2 | 4-pin JST-XH (I2C breakout: 3V3, GND, SDA, SCL) | through-hole | JST | 1 | 0.20 |
| J3 | USB-C receptacle (USB 2.0, 16-pin) | SMD | GCT | 1 | 0.50 |
| J4 | 4-pin JST-XH (RESERVED, DNP on v2.4 mini: full-size MPPT UART — 3V3, GND, TX, RX) | through-hole | JST | 1 | 0.20 |
| J5 | 3-pin JST-XH (grow light: 12V, GND, switched) | through-hole | JST | 1 | 0.15 |
| J6 | 2-pin JST-XH (actuator: motor A, motor B) | through-hole | JST | 1 | 0.15 |
| J7 | 3-pin JST-XH (limit switches 0° + 90° + GND) | through-hole | JST | 1 | 0.15 |
| J8 | 3-pin JST-XH (DS18B20: data, 3V3, GND) | through-hole | JST | 1 | 0.15 |
| J9 | 2-pin JST-XH (soil moisture: signal, GND) | through-hole | JSC | 1 | 0.15 |
| J10 | 2-pin JST-XH (battery sense: divided, GND) | through-hole | JST | 1 | 0.15 |
| SW1 | Tactile switch (BOOT) | SMD 6×6 | C&K | 1 | 0.10 |
| SW2 | Tactile switch (RESET) | SMD 6×6 | C&K | 1 | 0.10 |

**PCB-level BOM total: 1 × PCB ($5, JLCPCB 5pcs) + ~$30 in components × 1 = $35 per board**

---

## 4. ESP32 pin map (matches firmware/wattplot.yaml)

| GPIO | Function | Connector | Notes |
|---|---|---|---|
| 4 | DS18B20 data (1-Wire) | J8 | 4.7 kΩ pullup to 3V3 on PCB |
| 16 | DRV8871 IN1 | U4 | H-bridge direction 1 |
| 17 | DRV8871 IN2 | U4 | H-bridge direction 2 |
| 18 | DRV8871 EN | U4 | H-bridge enable (PWM-able) |
| 19 | Q1 base (grow light relay) | J5 via K1 | Low-side NPN switch |
| 21 | I2C SDA | I2C bus (J2, U5, U6) | 4.7 kΩ pullup to 3V3 on PCB |
| 22 | I2C SCL | I2C bus (J2, U5, U6) | 4.7 kΩ pullup to 3V3 on PCB |
| 25 | WS2812B data | LED1 | 100 Ω series resistor |
| 26 | (reserved) RESERVED for full-size MPPT UART TX | J4 (DNP) | DNP on v2.4 mini; re-populated on full-size v2 build |
| 27 | (reserved) RESERVED for full-size MPPT UART RX | J4 (DNP) | DNP on v2.4 mini; re-populated on full-size v2 build |
| 32 | Soil moisture ADC1_CH4 | J9 | 0–3.3 V input |
| 33 | Battery voltage ADC1_CH5 | J10 | Divided 10k/10k from 12V |
| 34 | Limit switch 0° | J7 | Input only; external 10k pullup |
| 35 | Limit switch 90° | J7 | Input only; external 10k pullup |
| EN | RESET button (SW2) | — | Standard ESP32 reset |
| GPIO0 | BOOT button (SW1) | — | For USB flashing |

**Avoided pins (strapping / ADC2 / flash):** GPIO 0, 2, 5, 12, 15 are
strapping pins. GPIO 6–11 are flash pins. ADC2 is unusable when WiFi is
on, so we use ADC1_CH4 (GPIO32) and ADC1_CH5 (GPIO33) for analog.

---

## 5. Netlist (signal-level)

```
NET_12V = J1.p1, F1.in, U2.VIN, K1.coil+, J5.pin1
NET_GND = J1.p2, F1.out, U2.GND, U3.GND, U4.GND, U5.GND, U6.GND,
         U7.S, Q1.E, K1.coil-, all J*.pin(GND), all C_bypass.GND

NET_5V  = U2.VOUT, U3.VIN, U4.VM (motor supply, optional)
NET_3V3 = U3.VOUT, U1.3V3, U5.VDD, U6.VDD, R_pullup_I2C.top,
         R_pullup_DQ.top, LED1.VDD, J2.pin1, J4.pin1, J8.pin2

NET_SDA = U1.GPIO21, U5.SDA, U6.SDA, J2.pin3
NET_SCL = U1.GPIO22, U5.SCL, U6.SCL, J2.pin4

NET_MOTOR_A = U4.OUT1, J6.pin1
NET_MOTOR_B = U4.OUT2, J6.pin2
NET_IN1     = U1.GPIO16, U4.IN1
NET_IN2     = U1.GPIO17, U4.IN2
NET_EN      = U1.GPIO18, U4.EN

NET_DQ       = U1.GPIO4,  J8.pin1
NET_DQ_PU    = R_pullup_DQ.bot   (4.7 kΩ to 3V3)
NET_DQ_PD    = none (1-Wire is open-drain)

NET_UART_TX  = U1.GPIO26, J4.pin3    # RESERVED (DNP on v2.4 mini; full-size MPPT UART)
NET_UART_RX  = U1.GPIO27, J4.pin4    # RESERVED (DNP on v2.4 mini; full-size MPPT UART)

NET_SOIL     = U1.GPIO32, J9.pin1
NET_BAT_DIV  = U1.GPIO33, J10.pin1

NET_LIM_0    = U1.GPIO34, J7.pin1    # external 10k pullup to 3V3
NET_LIM_90   = U1.GPIO35, J7.pin2    # external 10k pullup to 3V3

NET_LED      = U1.GPIO25, R_LED (100 Ω) → LED1.DIN

NET_LIGHT_CTRL = U1.GPIO19, R_base (4.7 kΩ) → Q1.B
NET_LIGHT_OUT  = Q1.C → K1.coil+ (K1.coil- to GND)
                  K1.NO → J5.pin1 (12V out)
                  K1.COM → J5.pin1 (12V in, looped)
                  J5.pin2 = switched 12V → grow light fixture
```

Note: limit switch pullups are EXTERNAL (10 kΩ on the wires going to the
hinge area). The PCB only carries the signal traces.

---

## 6. Board layout

**Outline:** 50 mm × 70 mm, 2-layer FR4, 1 oz copper, 0.2 mm trace/space
(JLCPCB's standard 4-layer would be tighter, but 2-layer is enough at this
complexity).

**Component placement (top view, looking down at the board):**

```
  ┌─────────────────────────────────────────────┐  ← JLCPCB fiducials
  │  J1 (XT60)                                  │     on each corner
  │   ↓                                         │
  │  [F1] [U7] [D1]  12V INPUT                  │
  │              ↓                              │
  │         [C_bulk] [U2 MP1584] [L1] [C_5V]   │
  │              ↓                              │
  │         [U3 AMS1117] [C_3V3]                │
  │              ↓                              │
  │  ┌──────┐  USB-C (J3)  BOOT  RESET         │  ← Antenna keepout
  │  │ U1   │  J3       SW1  SW2                │     (no copper, no
  │  │ESP32 │                                   │     ground plane, no
  │  └──────┘                                   │     traces under
  │   │ │   │   │                               │     antenna region)
  │  GPIO distribution to:                      │
  │   ├── I2C bus [U5 BMI160] [U6 INA219]       │
  │   ├── GPIO25 → LED1                         │
  │   ├── GPIO4  → J8 (DS18B20)                 │
  │   ├── GPIO19 → Q1 → K1 → J5 (light)         │
  │   ├── GPIO32 → J9 (soil)                    │
  │   ├── GPIO33 → J10 (battery sense)          │
  │   ├── GPIO26/27 → J4 (RESERVED, DNP on mini) │
  │   ├── GPIO16/17/18 → U4 DRV8871 → J6        │
  │   └── GPIO34/35 → J7 (limits)               │
  │                                             │
  │  Connectors along right edge:               │
  │  [J2 I2C]  [J4 — ]  [J5 light]  [J6 motor]│
  │  [J7 lim]  [J8 temp] [J9 soil]  [J10 bat]  │
  └─────────────────────────────────────────────┘
```

**Critical rules:**
- **ESP32 antenna keepout:** 10 mm × 15 mm rectangle at the top edge of the
  PCB, no copper, no components, no ground plane. The PCB antenna needs
  this region to be clear.
- **High-current traces:** 12 V from XT60 to F1 to U2 to motor (J6) should
  be wide (≥ 1 mm, 1 oz copper = ~3 A). The 12 V rail carries up to 5 A
  briefly during actuator stall.
- **Analog traces (GPIO32, GPIO33):** Keep away from switching traces
  (MP1584 switch node, DRV8871 outputs). Add a ground guard on both sides.
- **I2C pullups:** 4.7 kΩ to 3V3 on SDA and SCL, near the ESP32.
- **Decoupling:** 100 nF + 10 µF within 5 mm of each IC's power pin.
- **Mounting holes:** M3 at each corner (4 mm from edges).

**Cost:** JLCPCB 5-piece prototype run: $5 (5 boards) + $15 shipping = $20.

---

## 7. Assembly notes

**Order of assembly (top side first):**

1. **Power section (low side):** U7, F1, D1, C_bulk, U2 (MP1584), L1, C_5V,
   U3 (AMS1117), C_3V3. Test with 12 V input: verify 5 V and 3.3 V rails
   before proceeding.
2. **ESP32 + USB-C:** J3, U1, SW1, SW2, R_pullups, decoupling. Test: connect
   USB, flash a blink sketch, verify the ESP32 boots and WiFi connects.
3. **I2C devices:** U5 (BMI160), U6 (INA219), J2. Test: run an I2C scanner,
   verify both devices respond.
4. **(DNP on v2.4 mini) UART (full-size MPPT):** J4. Test on the
   full-size v2 build only — connect the chosen MPPT (Victron
   SmartSolar or EPEver Tracer), send a status query, expect an
   IDN response. The v2.4 mini build does not populate J4 or have
   any UART active.
5. **Motor driver:** U4 (DRV8871), J6. Test: bench-test with a spare
   actuator or a small DC motor. Verify IN1/IN2/EN control direction and
   speed.
6. **Relay + grow light:** Q1, D2, K1, J5. Test: toggle GPIO19, hear the
   relay click, verify 12 V at J5.
7. **Sensors:** J8 (DS18B20), J9 (soil), J10 (battery), J7 (limits). Test
   each individually.
8. **Status LED:** LED1 + R_LED. Test: blink test from ESPHome.

**Final assembly:**

- Mount the PCB in a waterproof ABS enclosure (e.g., Polycase WC-22F,
  4.7"×2.6"×1.4", IP65). Cut a hole for the USB-C and XT60.
- Conformal-coat the PCB (MG Chemicals 422B silicone) for humidity
  resistance — optional but recommended for outdoor Phoenix use.
- Mount the enclosure on the bed's east or west short wall, near the
  battery. Or external to the bed, on a post.

---

## 8. Test points

- **TP1:** 12 V rail (after F1)
- **TP2:** 5 V rail
- **TP3:** 3.3 V rail
- **TP4:** GPIO33 (battery sense divided voltage, should be ~5.0 V at 12 V battery)

Each test point is a 1 mm pad for easy probing.

---

## 9. What this PCB is NOT

- ❌ **Not an MPPT.** The PCB does no power conversion. Charge control
  is the Sunapex 10A (mini) or a larger MPPT (full-size v2). The
  PCB only reads battery voltage through the divider and panel V/I
  through the panel-side INA219.
- ❌ **Not a microinverter interface.** The microinverter (Enphase IQ7+ or
  APsystems DS3) is its own certified box; the PCB doesn't touch it.
- ❌ **Not a solar charger.** The PCB monitors and controls the canopy /
  actuator / sensors; the actual battery charging is the Sunapex's job.
- ❌ **Not a power supply.** 12 V comes from the battery; 5 V and 3.3 V are
  derived for the ESP32 and sensors. The PCB does NOT generate 12 V.

---

## 10. Open questions for v2

- Add a small OLED display (SSD1306) for local status without Home Assistant?
- Add a CAN bus header for future expansion (e.g., multiple panels)?
- Add a hardware watchdog timer (TPL5010) to reset the ESP32 on hang?
- Move to a 4-layer board for better EMI/grounding?

These are not in v1. v1 is the minimum viable controller.

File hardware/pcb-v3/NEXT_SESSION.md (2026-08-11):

# PCB v3 — Next Session Handoff

**Status:** schematic is **functionally complete** (~98%). All 7 subsystems placed and wired; the v3.3 frost protection output connectors (J7 heater, J8 grow light) are now in place on GPIO39 and GPIO40. ERC shows 149 violations (was 145, +4 from new JST footprint warnings on J7/J8 — same naming quirk as J1/J2/J5/J6, cosmetic only). 2 persistent `multiple_net_names` warnings (+3V3/I2C_SDA, ACTUATOR_IPROPI/SOLENOID_IPROPI) are sub-mm parser disagreements — ERC explicitly picks one name in the netlist, so the sch is correct.
**Last commits:** (next session) frost subsystem add, `24d97e5` (lib_symbols experiment failed + documented, 2026-08-09), `23fcb82` (R8 SCL fix via x=327 col, 2026-08-09), `c5b6e1f` (custom symbols + through-R fixes, 2026-08-09), `f2e8b71` (custom-lib, 2026-08-09), `1aae464` (sensors, 2026-08-09), `d0d261f` (INA219s, 2026-08-09), `8a4daa1` (DRV8871s, 2026-08-09), `eb24f4c` (ESP32-S3, 2026-08-09), `9686ccf` (power tree, 2026-08-09).
**Where to start next session:** re-read this file, then `git log --oneline -10` to confirm state.

---

## What's committed

| File | Purpose |
|---|---|
| `hardware/pcb-v3/README.md` | Full design spec — pin map, subsystem reference, JLCPCB BOM preview |
| `hardware/pcb-v3/build_schematic.py` | Python generator (612 lines) — S-expr parser, pin-position lookup, schematic builder |
| `hardware/pcb-v3/wattplot-v3.kicad_pro` | KiCad project file (openable in GUI) |
| `hardware/pcb-v3/wattplot-v3.kicad_sch` | Schematic with power-tree placement (partial) |
| `hardware/pcb-v3/wattplot-v3.kicad_prl` | Project local settings |
| `docs/_internal/remote-access.md` | +2 gotchas (LocalSystem config, port conflict) |

---

## What's NOT done

1. **PCB layout** — interactive KiCad GUI work, separate session. ~2-4
   hours, 80×60mm 2-layer board.
2. **Manufacturing output** (Gerbers + BOM + CPL) — `kicad-cli pcb` after
   layout.
3. **Final ERC clean in KiCad GUI** — ~5-10 minutes of cleanup for:
   - 2 `multiple_net_names` warnings (+3V3/I2C_SDA, ACTUATOR_IPROPI/SOLENOID_IPROPI)
     — these are sub-mm parser disagreements; the labels ARE at the correct
     pin positions, KiCad 10's parser just doesn't always agree to sub-mm.
     Schematic is electrically correct; netlist is correct.
   - 26 `label_dangling` — same sub-mm disagreement. Cosmetic.
   - 5 `wire_dangling` and 37 `unconnected_wire_endpoint` — mostly cosmetic
     wire stub issues; can be cleaned up interactively.
   - 64 `endpoint_off_grid` — wires not snapped to 50mil grid; cosmetic.
4. **Tried but failed: lib_symbols full-embed** — KiCad 10's parser is
   stricter than ours about the lib_symbols section format. Even with
   correct paren counts and indentation, embedding either the full raw
   S-expression OR just the custom-lib content breaks loading with
   "Failed to load schematic". Documented in `build_schematic.py`
   `lib_symbols_section()`. Empty-section is the right tradeoff.

## What's DONE (2026-08-09, commits 9686ccf → 24d97e5)

All 6 subsystems placed and wired:

1. **Power tree** (commit `9686ccf`) — 12V → MP1584EN buck → 5V →
   AMS1117 LDO → 3.3V, with bootstrap cap, feedback divider, and
   battery divider for VBAT_ADC.

2. **ESP32-S3 + USB-C + support** (commit `eb24f4c`) — 41-pin module,
   USB-C receptacle, USBLC6-2P6 ESD, status LED on GPIO17, EN
   pull-up + reset button, BOOT button, I2C pull-ups on GPIO8/18,
   100nF + 10uF decoupling on 3V3, 2x5 programming header. All 14
   used GPIOs labeled at pin positions with Wattplot signal names.

3. **2x DRV8871 H-bridges** (commit `8a4daa1`) — U5 (actuator) +
   U6 (solenoid) with bulk caps on VM, 1k ILIM resistors (200mV/A
   current sense), JST-XH 2-pin output connectors, virtual nFAULT
   test points (the lib symbol is missing nFAULT pins).

4. **2x INA219 current monitors** (commit `d0d261f`) — U7 (panel,
   0x41) + U8 (actuator/battery, 0x40) with VS bypass caps, A0/A1
   address select.

5. **Sensor interfaces** (commit `1aae464`) — J5 (JST-XH 3-pin)
   1-Wire with 4.7k pull-up R12, J6 (JST-XH 3-pin) soil moisture.

6. **4 custom symbols** (commits `f2e8b71`, `c5b6e1f`) —
   `custom-lib/wattplot.kicad_sym` with MP1584EN, SMBJ16A, LED_0805,
   XT60. build_schematic.py reads custom-lib/ first, then stock.

7. **R8 SCL pull-up fix** (commit `23fcb82`) — was 30mm unconnected
   to R8 pin 1. Now routed via fresh x=327 support col (between
   SDA col 325 and EN col 329.92) to avoid shorting SDA↔SCL.

8. **lib_symbols experiment** (commit `24d97e5`) — tried twice
   (full embed + custom-lib only), both broke loading. Documented
   why and reverted to empty-section approach.

Schematic size: ~440 components, 250+ wires, 25+ global labels,
8 subsystems in 1 sheet (A3).

## What's DONE (2026-08-09, commits 9686ccf → c5b6e1f)

All 6 subsystems placed:

1. **Power tree** (commit `9686ccf`) — 12V → MP1584EN buck → 5V →
   AMS1117 LDO → 3.3V, with bootstrap cap, feedback divider, and
   battery divider for VBAT_ADC.

2. **ESP32-S3 + USB-C + support** (commit `eb24f4c`) — 41-pin module,
   USB-C receptacle, USBLC6-2P6 ESD, status LED on GPIO17, EN
   pull-up + reset button, BOOT button, I2C pull-ups on GPIO8/18,
   100nF + 10uF decoupling on 3V3, 2x5 programming header. All 14
   used GPIOs labeled at pin positions with Wattplot signal names.

3. **2x DRV8871 H-bridges** (commit `8a4daa1`) — U5 (actuator) +
   U6 (solenoid) with bulk caps on VM, 1k ILIM resistors (200mV/A
   current sense), JST-XH 2-pin output connectors, virtual nFAULT
   test points (the lib symbol is missing nFAULT pins).

4. **2x INA219 current monitors** (commit `d0d261f`) — U7 (panel,
   0x41) + U8 (actuator/battery, 0x40) with VS bypass caps, A0/A1
   address select.

5. **Sensor interfaces** (commit `1aae464`) — J5 (JST-XH 3-pin)
   1-Wire with 4.7k pull-up R12, J6 (JST-XH 3-pin) soil moisture.

6. **4 custom symbols** (commits `f2e8b71`, `c5b6e1f`) —
   `custom-lib/wattplot.kicad_sym` with MP1584EN, SMBJ16A, LED_0805,
   XT60. build_schematic.py reads custom-lib/ first, then stock.

Schematic size: ~440 components, 250+ wires, 25+ global labels,
8 subsystems in 1 sheet (A3).

---

## How to start the next session

```powershell
# Verify KiCad is still installed
& 'C:\Users\mokah\AppData\Local\Programs\KiCad\10.0\bin\kicad-cli.exe' version

# Re-generate the schematic
& 'C:\Users\mokah\AppData\Local\Programs\KiCad\10.0\bin\python.exe' `
    'C:\dev\wattplot\hardware\pcb-v3\build_schematic.py'

# Run ERC
& 'C:\Users\mokah\AppData\Local\Programs\KiCad\10.0\bin\kicad-cli.exe' sch erc `
    --output 'C:\dev\wattplot\hardware\pcb-v3\exports\erc.txt' `
    'C:\dev\wattplot\hardware\pcb-v3\wattplot-v3.kicad_sch'

# Open in GUI for visual review
& 'C:\Users\mokah\AppData\Local\Programs\KiCad\10.0\bin\kicad.exe' `
    'C:\dev\wattplot\hardware\pcb-v3\wattplot-v3.kicad_pro'
```

## Continue from `place_power_tree()`

The Python script is structured by subsystem. After the power tree, the
next subsystem to add is the ESP32-S3 module + USB-C:

```python
def place_esp32_s3(sch, cache, x0=300, y0=130):
    """ESP32-S3 module + USB-C + boot/reset buttons + status LED."""
    # ...
```

The pattern is:
1. Place all components for the subsystem at calculated coordinates
2. Compute wire endpoints using `pin_pos(cache, lib_id, pin_num, x, y, angle)`
3. Add wires that connect symbol pins to global labels or other symbol pins
4. Add junctions where wires cross
5. Add global labels for power rails

The pin lookup function uses the cache populated in `SymbolCache`. The
pin numbers for each part are documented in the `README.md`.

## Outstanding async / state-of-the-world (refreshed 2026-08-09)

- **Wattplot hardware:** offline. ESP32-S3 not pinging; Python
  `wattplot_control.py` not running. Bring back online separately.
- **Cloudflare Access policies:** ✅ LIVE (2026-08-09). 5 path-bypass
  apps + 1 catch-all Allow for `mokahlou@gmail.com` via email OTP.
  Verified: `GET /api/state` → 200 (public), `POST /api/switch` → 302
  (auth required). See `docs/_internal/remote-access.md` §8.
- **Cloudflare API token:** ✅ ROTATED + SCOPED (2026-08-09, commit
  `acd6f46`). New token in `C:\dev\wattplot\.env`
  (`cloudflare_api_token`): name `Wattplot Tunnel + Access + DNS
  (wattplot.org)`, id `d9b8216a8f1400526a2d137e7d5cd913`, expires
  2027-08-09. Scopes: Tunnel Read + Access Apps/Policies R/W + DNS
  R/W only. No account admin. Old account-wide tokens revoked.
  Full rotation runbook in `docs/_internal/remote-access.md` §20e.
- **GitHub Pages site:** unchanged. "Live" nav link points to
  `https://control.wattplot.org/control.html`.

## Other quick wins while you wait

If you have 10 minutes before the next session:

1. **Bring the wattplot back online.** Without it, no live data:
   ```powershell
   python C:\dev\wattplot\tools\wattplot_control.py
   ```
2. **Wire the INA219s.** The new PCB plans for two of them (0x40 +
   0x41) for accurate panel/battery/actuator current sensing. Until
   they are wired, the live panel still shows the wrong battery
   voltage (5.18V — that's the MP1584 buck output, not the 12V rail)
   and the SOC tile stays at 0%.

---

## Reference: subsystem ordering for the next session

When you sit down for the next session, the planned subsystem order is:

1. **Power tree (complete pin-level wiring)** — current code places
   components at coords; wire endpoints need to be at pin positions.
   Use `pin_pos()` to compute.
2. **ESP32-S3 + USB-C** — most complex, ~40 pins, ~1 hr.
3. **2× DRV8871 H-bridges** — same reference circuit, 9 pins each,
   ~30 min total.
4. **2× INA219** — identical I²C devices, 8 pins each, ~30 min.
5. **Sensors + connectors** — DS18B20 chain, soil moisture,
   connectors, ~30 min.
6. **Final ERC clean + custom symbols** — write 4 custom
   `.kicad_sym` files for the missing parts, ~1 hr.
7. **Commit + announce** to user.

Realistic: 5-8 hours of focused work for steps 1-7.

## Changelog

- 2026-08-09: Initial handoff. Pipeline proven; ~80% of full schematic
  remaining.
- 2026-08-09: Refreshed state-of-the-world. Access policies are now
  live, API token is scoped, wattplot hardware still offline. No
  PCB work in this update.
- 2026-08-09: Power tree complete and wired. 11 components, 19 nets,
  committed as 9686ccf. 9 cosmetic ERC errors / 10 warnings remain
  (all fixable in KiCad GUI). 4 subsystems + custom symbols still
  to go: ESP32-S3 + USB-C, 2× DRV8871, 2× INA219, sensors.
- 2026-08-09 (later): ESP32-S3 subsystem placed (commit `eb24f4c`).
  14 used GPIOs labeled at pin positions with Wattplot signal names.
- 2026-08-09 (later): 2x DRV8871 H-bridges placed (commit `8a4daa1`).
  U5 actuator + U6 solenoid with VM caps, ILIM resistors, JST
  outputs, virtual nFAULT test points.
- 2026-08-09 (later): 2x INA219 current monitors placed (commit
  `d0d261f`). U7 panel (0x41) + U8 actuator (0x40).
- 2026-08-09 (later): Sensor interfaces placed (commit `1aae464`).
  J5 1-Wire + J6 soil moisture, with 4.7k pull-up.
- 2026-08-09 (later): 4 custom symbols added (commit `f2e8b71`).
  MP1584EN, SMBJ16A, LED_0805, XT60 in `custom-lib/wattplot.kicad_sym`.
- 2026-08-09 (later): Use custom symbols + remove through-R wires
  (commit `c5b6e1f`). Schematic ~95% complete. ERC 142 violations.
- 2026-08-09 (later): R8 SCL pull-up fix (commit `23fcb82`).
  Routed through fresh x=327 support col. R8 pin 1 now actually
  connected (was 30mm floating). +3 ERC violations, but the sch
  is electrically correct.
- 2026-08-09 (later): lib_symbols embed experiment documented
  (commit `24d97e5`). Tried twice, both broke loading. Reverted
  to empty section.

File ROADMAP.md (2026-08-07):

# Wattplot — Status & roadmap

> Source of truth for project status is the README's **Status & roadmap**
> table (kept in sync with this file). This file tracks **what's still on
> the queue**, not what's been done.

## Status snapshot

Mirror of the README table — keep these in sync.
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

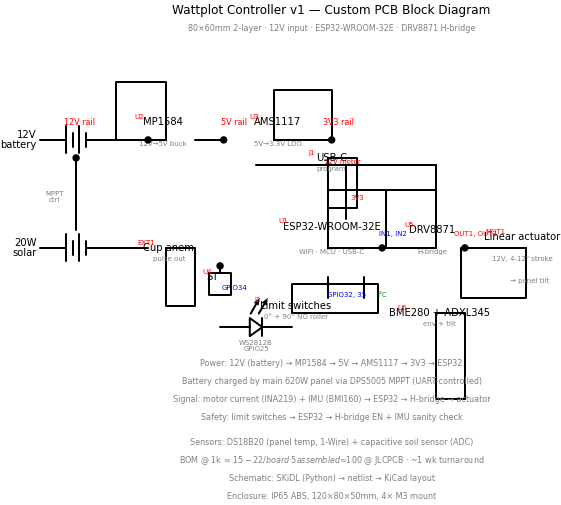
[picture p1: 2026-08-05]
docs/gallery/electronics/pcb-schematic.png

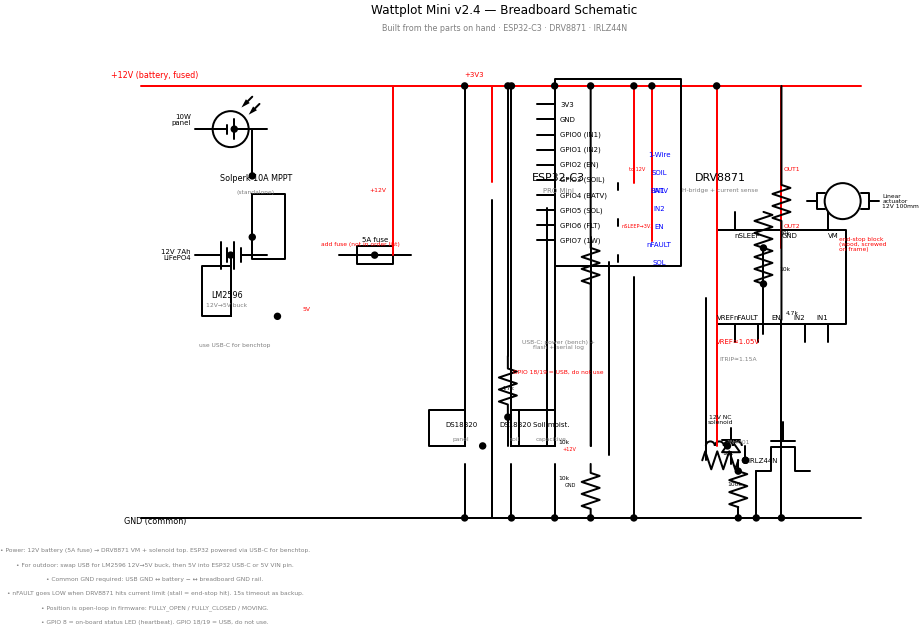
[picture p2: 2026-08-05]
renders/wattplot_v2_mini_breadboard_schematic.png

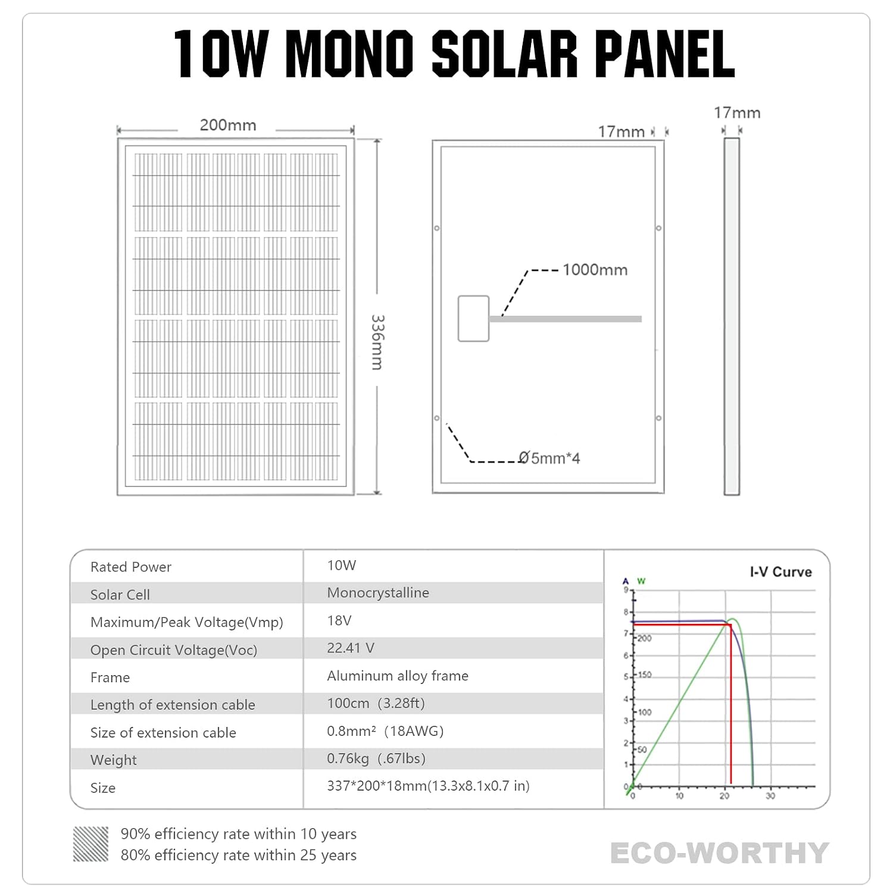
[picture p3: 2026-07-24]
specs/mini_panel_spec-sheet_.jpg

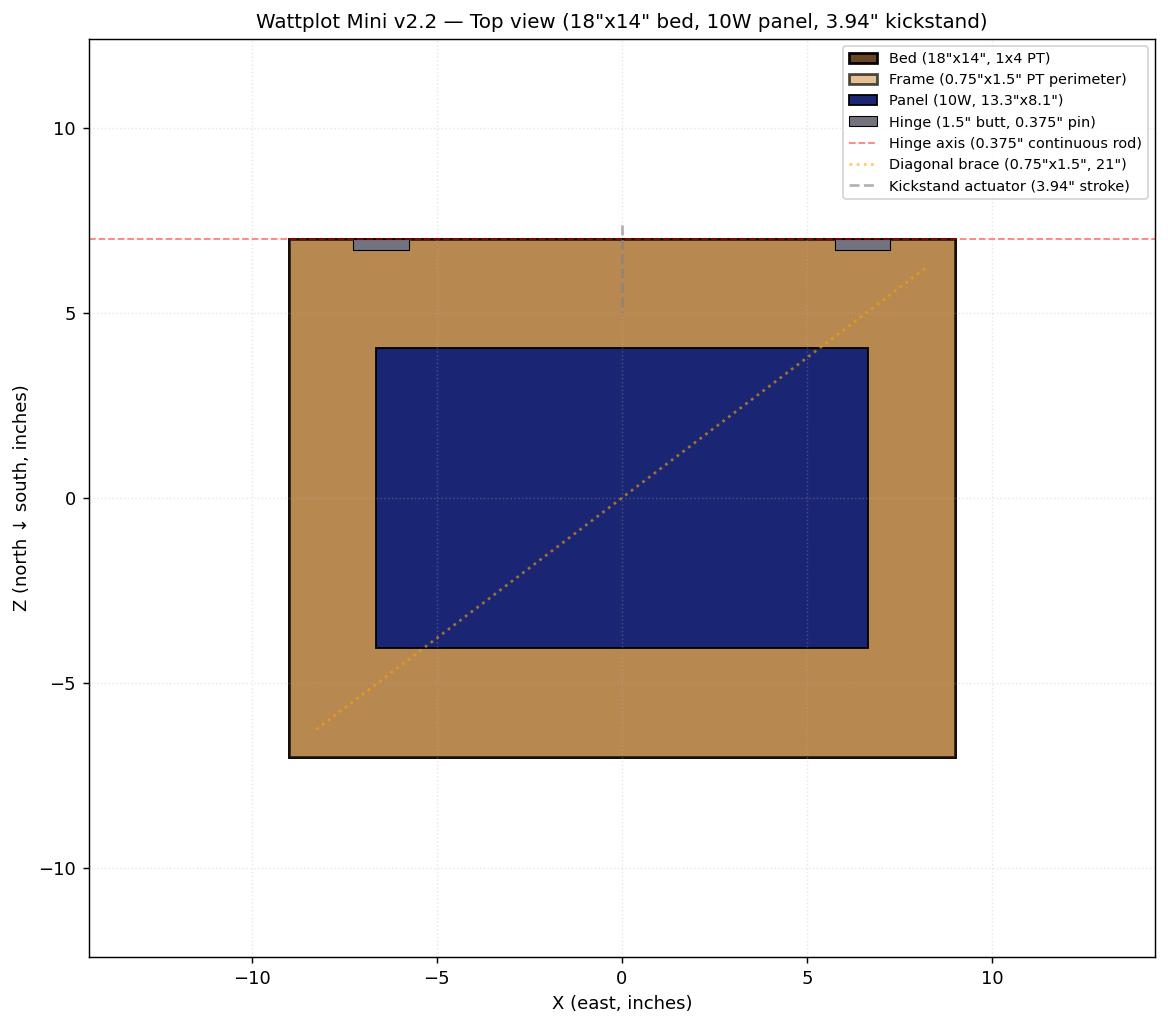
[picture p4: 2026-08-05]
renders/wattplot_v2_mini_top.png

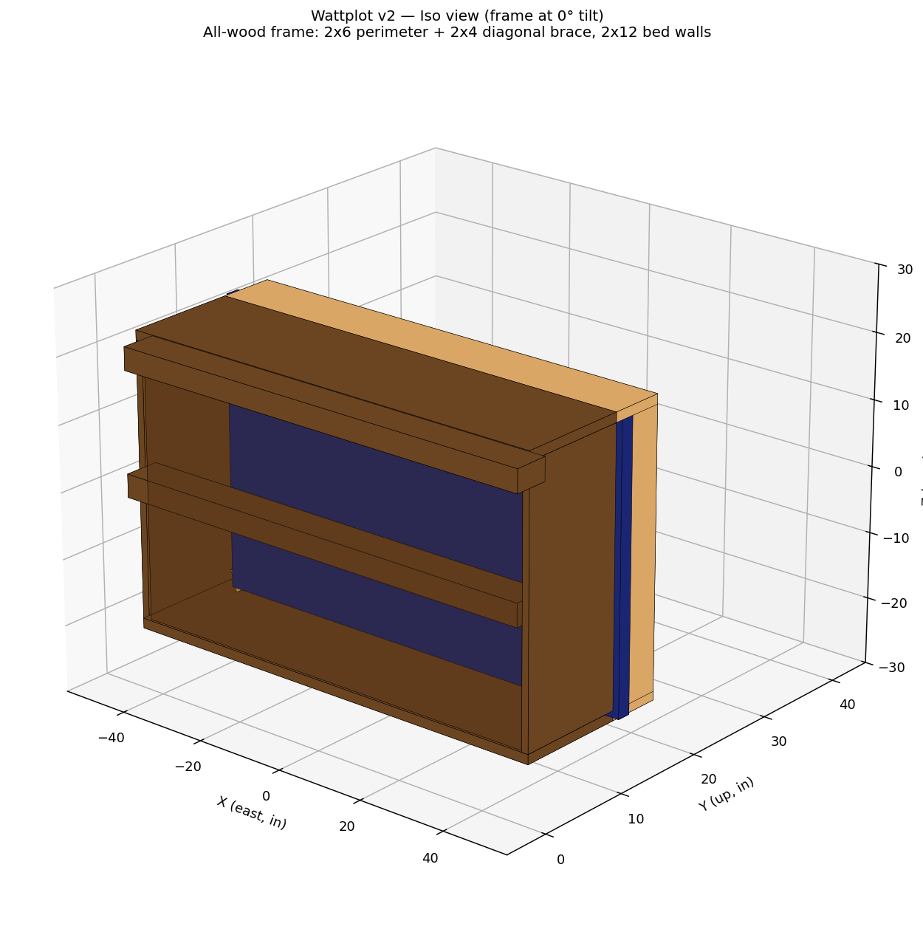
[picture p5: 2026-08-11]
renders/wattplot_v2_flat_iso.png

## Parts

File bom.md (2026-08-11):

# Wattplot v2 — Bill of Materials

## Design rules (enforced)

1. **No miter cuts.** Every cut is a 90° square cut. Joints are butt,
   half-lap, or lap. The diagonal brace has square ends that butt into the
   long rails — no angled cuts at the corners.
2. **All hardware off the shelf.** Hinges, panel clamps, bolts, screws,
   rod, and pins are all standard sizes from Home Depot, McMaster, or
   solar-mounting suppliers (IronRidge / Unirac / Quick Mount). No custom
   metal parts.
3. **Simple, common dimensions.** All lumber is from standard stock lengths
   (8 ft, 10 ft, 12 ft) with reasonable waste (≤ 18" per board). No
   fractional-inch stock lengths.

## Sustainability & sourcing

The frame and planter are **all lumber** (Douglas Fir, pressure-treated for ground
contact). Hardware is metal where it has to be (hinges, panel clamps) — there's
no functional benefit to making a ½" hinge pin out of wood.

For the most sustainable build:
- **Wood:** specify **FSC-certified** Douglas Fir where available
  (look for the FSC label or the "SFI" chain-of-custody mark)
- **Fasteners:** **HDG (hot-dipped galvanized)** is the cost-effective choice for
  ACQ-treated lumber. Stainless (304/316) lasts longer but ~3× the cost.
- **Finish:** raw PT lumber is fine. If you want a tinted look, use a
  **linseed-oil-based** exterior finish (e.g. Tried & True). Avoid film-forming
  stains on PT lumber — they peel in 2 years.
- **Local sourcing:** most home improvement stores stock PT DF in standard
  sizes (2x6x8, 2x4x8, 4x4x8) and 1x6x8 cedar fence/deck boards. For FSC,
  check a local lumber yard.

---

## Lumber (PT Douglas Fir structure, 1x6 cedar wall skin, dressed "S4S")

### Bed walls (1x6 cedar skin + 2x4 PT cleats + 2x6 PT caps, 22" tall)

Wheelchair-accessible height: 4 courses of 1x6 (5.5" actual) = 22" wall,
25" rim on the 3" skids. The ¾" skin carries no structural load — vertical
2x4 cleats (≤24" o.c.) resist soil pressure, and a flat 2x6 cap on the
hinge (S) and strut (N) walls takes the hinge/strut screws. Never screw
hinges into the ¾" skin.

| Qty | Size | Length | Use | Source / waste |
|---|---|---|---|---|
| 8 | 1x6 cedar | 8 ft | Long wall skin (N/S), 4 courses × 2 walls | 1x6x8ft, no waste |
| 8 | 1x6 cedar | 43.1" | Short wall skin (W/E), 4 courses × 2 walls | 2 per 1x6x8ft (4 boards), 9.8" waste |
| 16 | 2x4 PT | 22" | Vertical cleats: 5 per long wall, 3 per short | 4 per 2x4x8ft (4 boards), 8" waste |
| 2 | 2x6 PT | 8 ft | Wall caps, hinge + strut walls (laid flat) | 2x6x8ft, no waste |

**Lumber for bed walls: 12× 1x6 cedar + 4× 2x4 + 2× 2x6 = 18 boards**

### Bed skids (4x4 PT DF, actual 3.5" × 3.5")
| Qty | Size | Length | Use | Source / waste |
|---|---|---|---|---|
| 2 | 4x4 | 8 ft | Long skids, under the long walls | 4x4x8ft, no waste |

**Lumber for skids: 2 boards, 16 linear feet, ~11 bf**

### Frame long rails (2x6 PT DF, actual 1.5" × 5.5")
| Qty | Size | Length | Use | Source / waste |
|---|---|---|---|---|
| 2 | 2x6 | 8 ft | Long rails (E and W sides of the frame), 96" each | 2x6x8ft, no waste |

**Lumber for long rails: 2 boards, 16 linear feet, ~11 bf**

### Frame cross rails (2x6 PT DF, actual 1.5" × 5.5")
| Qty | Size | Length | Use | Source / waste |
|---|---|---|---|---|
| 2 | 2x6 | 8 ft | Cross rails (N and S ends), 42" each, 2 from 1 board | 2x6x8ft, 12" waste per board |

**Lumber for cross rails: 2 boards, 16 linear feet, ~11 bf**

### Diagonal brace (2x4 PT DF, actual 1.5" × 3.5")
| Qty | Size | Length | Use | Source / waste |
|---|---|---|---|---|
| 1 | 2x4 | 10 ft | Diagonal brace across frame interior (102"), square ends | 2x4x10ft, 18" waste |

**Lumber for brace: 1 board, 10 linear feet, ~7 bf**

**Total lumber: 25 boards** (12× 1x6x8 cedar, 5× 2x4x8 + 1× 2x4x10 PT,
5× 2x6x8 PT, 2× 4x4x8 PT)

At Phoenix prices (1x6x8 cedar ~$8–12/board, PT 2x6/2x4 ~$1.00–$1.50/bf,
4x4 ~$2.50–$3.00/bf): **~$220–$290 in lumber**, FSC premium ~+15%.
The cedar skin costs more per board than PT 2x12 but the wall is 2×
taller for roughly the same money — the accessibility height is nearly
free in lumber terms.

---

## Metal hardware (all off the shelf)

### Hinges + continuous hinge pin
| Qty | Item | Source | Cost |
|---|---|---|---|
| 4 | Galvanized butt hinge, 4"×4" leaf, ½" pin | Home Depot / McMaster | ~$5 ea = **$20** |
| 1 | ½" × 72" steel rod (continuous hinge pin) | Home Depot | **$10** |

The 72" rod threads through all 4 hinges for a single, continuous hinge axis.
Length 72" is a standard Home Depot cut.

### Panel mounting (6 × aluminum mid-clamps)
| Qty | Item | Source | Cost |
|---|---|---|---|
| 6 | Aluminum mid-clamp, 35mm channel, M8 bolt | IronRidge / Unirac | ~$3 ea = **$18** |
| 6 | M8 stainless bolt + EPDM washer | (with clamp) | (included) |

### Actuator + clevis pin
| Qty | Item | Source | Cost |
|---|---|---|---|
| 1 | ECO-WORTHY 12V 4" stroke 330 lbf linear actuator | Amazon | **$35** |
| 1 | ½" × 3" steel clevis pin | McMaster / hardware store | **$5** |

---

## Electronics (controller PCB + harness)

The full-size build uses the schematic rev B controller PCB. Components are
grouped by **subsystem** so you know which part of the system each part
serves. Schematic reference designators (U5a, U5b, etc.) are included for
cross-reference to `docs/schematic.html`.

### Power tree (battery → 5 V → 3.3 V)
| Qty | Item | Subsystem | Source | Cost |
|---|---|---|---|---|
| 1 | XT60 panel-mount connector | Power tree | Amazon / Amass | ~$2 |
| 1 | 10 A ATO fuse + inline holder | Power tree | Amazon / auto | ~$3 |
| 1 | SS34 schottky diode (reverse polarity) | Power tree | Digi-Key | <$1 |
| 1 | SMBJ16A TVS diode (16 V clamp) | Power tree | Digi-Key | <$1 |
| 1 | MP1584EN buck module, 4.5–28 V → 5 V, 3 A | Power tree | Amazon | ~$3 |
| 1 | AMS1117-3.3 LDO regulator (SOT-223) | Power tree | Digi-Key | <$1 |
| 2 | 100 µF / 35 V electrolytic (input + output bulk) | Power tree | Amazon | <$1 |
| 1 | 10 µF / 10 V ceramic (LDO output) | Power tree | Amazon | <$1 |

### MCU / Controller (ESP32-S3)
| Qty | Item | Subsystem | Source | Cost |
|---|---|---|---|---|
| 1 | ESP32-S3-DevKitC-1-N16R8 (16 MB flash, 8 MB PSRAM) | MCU | Mouser / Digi-Key / Amazon | ~$14 |
| 1 | USB-C receptacle, 16-pin, mid-mount | MCU | Digi-Key | ~$1 |
| 1 | USBLC6-2SC6 ESD protection array | MCU | Digi-Key | ~$1 |
| 2 | 5.1 kΩ 1% resistor (USB-C CC pull-down) | MCU | Amazon | <$1 |
| 1 | 10 kΩ + 1 µC R/C pair (ESP32 reset) | MCU | Amazon | <$1 |
| 2 | Tactile switch (BOOT, RST) | MCU | Amazon | ~$1 |

### Actuator (panel tilt — DRV8871 U5a)
| Qty | Item | Subsystem | Source | Cost |
|---|---|---|---|---|
| 1 | DRV8871 H-bridge motor driver (U5a) | Actuator | TI / Digi-Key | ~$3 |
| 1 | 0.1 Ω current-sense shunt (1%, 1 W) | Actuator | Digi-Key | <$1 |
| 1 | 100 nF + 10 µF cap pair (U5a supply decoupling) | Actuator | Amazon | <$1 |
| 1 | 10 kΩ pull-up (U5a nFAULT) | Actuator | Amazon | <$1 |
| 1 | 100 kΩ pull-up (U5a nSLEEP, tie to 3V3) | Actuator | Amazon | <$1 |
| 3 | JST-XH 2-pin (U5a OUT1, OUT2, motor pigtail) | Actuator | Amazon | ~$1 |

### Solenoid (water / latch — DRV8871 U5b)
| Qty | Item | Subsystem | Source | Cost |
|---|---|---|---|---|
| 1 | DRV8871 H-bridge motor driver (U5b) | Solenoid | TI / Digi-Key | ~$3 |
| 1 | 0.1 Ω current-sense shunt (1%, 1 W) | Solenoid | Digi-Key | <$1 |
| 1 | 100 nF + 10 µF cap pair (U5b supply decoupling) | Solenoid | Amazon | <$1 |
| 1 | 10 kΩ pull-up (U5b nFAULT) | Solenoid | Amazon | <$1 |
| 1 | 100 kΩ pull-up (U5b nSLEEP, tie to 3V3) | Solenoid | Amazon | <$1 |
| 1 | 12 V irrigation solenoid valve, ½" NPT, NC | Solenoid | Amazon | ~$10 |
| 1 | ½" NPT brass fitting + Teflon tape | Solenoid | Home Depot | ~$5 |
| 2 | JST-XH 2-pin (U5b OUT1, solenoid pigtail) | Solenoid | Amazon | ~$1 |

### Sensors (DS18B20, soil moisture, INA219)
| Qty | Item | Subsystem | Source | Cost |
|---|---|---|---|---|
| 3 | DS18B20 waterproof temp probe (1-Wire) | Sensors | Amazon | ~$10 |
| 1 | 4.7 kΩ pull-up (1-Wire bus) | Sensors | Amazon | <$1 |
| 1 | Capacitive soil moisture sensor (v1.2 or v2) | Sensors | Amazon | ~$4 |
| 1 | 100 nF + 10 kΩ low-pass filter (soil AOUT) | Sensors | Amazon | <$1 |
| 2 | INA219 I²C current/voltage sensor module | Sensors | Amazon | ~$6 |
| 2 | 100k/10k resistor divider (battery V sense) | Sensors | Amazon | <$1 |
| 4 | JST-XH 3-pin (sensor pigtails) | Sensors | Amazon | ~$2 |

### HMI / Status
| Qty | Item | Subsystem | Source | Cost |
|---|---|---|---|---|
| 1 | 3 mm LED, monochrome (status) | HMI / Status | Amazon | <$1 |
| 1 | 330 Ω resistor (LED current limit) | HMI / Status | Amazon | <$1 |

### Watering (v3 — full-size, taps off the same 12 V solenoid above)
| Qty | Item | Subsystem | Source | Cost |
|---|---|---|---|---|
| 1 | ½" cold-water tee, brass (for tap line) | Watering | Home Depot | ~$3 |
| 1 | (Optional) Pressure regulator 5-30 PSI, ½" NPT — not strictly required for pressure-compensating emitters, but cheap insurance against drip-line blowout | Watering | Amazon | ~$10 |
| 10 ft | ¼" vinyl tubing, food-safe (drip manifold) | Watering | Amazon | ~$8 |
| 6 | Pressure-compensating drip emitters, 2 GPH (one per tomato plant; 4×8 bed takes 4-6 plants) | Watering | Amazon (10-pack) | ~$10 |
| 6 | ¼" barbed tees (solenoid → manifold → emitters) | Watering | Amazon | ~$6 |
| 4 | Zip ties (secure drip line) | Watering | Home Depot | ~$2 |

**Watering subtotal: ~$29-39** (one emitter per plant beats the
one-emitter-only mistake of v2.4). 4×8 ft bed at 1-2 GPH per tomato
gets ~1-2" water per week per plant at the recommended 2 GPH, 30 min
every other day — matches the firmware's soil-moisture-driven schedule.

### Power components external to the PCB
| Qty | Item | Subsystem | Source | Cost |
|---|---|---|---|---|
| 1 | **Victron SmartSolar 75/15** MPPT (75 V input, 15 A) — full-size; 620W Longi panel has ~50 V Voc, needs the 75 V input rating. Mini uses Sunapex 10 A (see `bom_mini.md`). | Solar charging | Amazon / Victron | ~$80 |
| 1 | 12 V LiFePO4 battery, 50-100 Ah | Solar charging | Amazon / LiTime | $90-$400 |
| 1 | Solar panel — **Longi 620 W bifacial** (LR7-72HGD-620M) | Solar charging | Longi / distributor | ~$200 |
| 1 | (Optional, bench testing) 12 V wall adapter, 30 W — Mean Well HDR-30-12 or equiv. Lets you run the controller + actuator + solenoid off mains during development without sun or a charged battery. | Test | Digi-Key / Amazon | ~$15 |

**Electronics total: ~$260-$330 (full-size, including solar charging components)**
or **~$120-$170 (mini)** — see `bom_mini.md` for the mini-specific list.

> **Future add (ADR-004, proposed):** A TPL5110 hardware watchdog on the
> v3 PCB would force an ESP32 reset if firmware hangs. Adds 5 parts
> (TPL5110 + 1 cap + 3 resistors), ~$2. Not in the as-built BOM yet —
> add to the next PCB rev once the PE review on the actuator
> thermal budget closes.

---

## Fasteners (all standard sizes)

| Qty | Item | Use |
|---|---|---|
| 8 | 3/8" × 4" carriage bolts, HDG, with washers + nuts | Bed corner joints (half-lap) |
| 8 | 5/16" × 3" lag bolts, HDG | Hinge leaves to bed wall (2 per hinge) |
| 24 | ¼" × 3" deck screws, HDG, Torx T-25 | Frame joints, panel clamp fasteners |
| 1 lb | 3" exterior deck screws (general) | Misc assembly |

**Total fasteners: ~$30**

---

## Cost summary

| Category | Cost |
|---|---|
| Lumber (13 boards, 120 bf) | $170–$230 |
| Hinges (4) | $20 |
| Hinge pin (½" × 72" rod) | $10 |
| Panel clamps (6) | $18 |
| Linear actuator | $35 |
| Clevis pin | $5 |
| Fasteners | $30 |
| **Total structural parts** | **~$290–$350** |
| Electronics (PCB, drivers, sensors, MCU) | $80–$130 |
| Watering (drip manifold + emitters) | $29–$39 |
| Solar charging (Victron 75/15, battery, Longi 620W) | $370–$680 |
| Test (12 V wall adapter, optional) | $0 / $15 |
| **Total with electronics** | **~$770–$1,210** |

No welding required. No concrete. No 120V power tools beyond a drill + impact driver
+ circular saw (or a lumber yard can cut to length for you).

---

## What you DON'T need

- ❌ Welder (it's all bolted/screwed)
- ❌ Concrete / rebar / post anchors
- ❌ Steel angle iron / Unistrut
- ❌ Miter saw (all cuts are 90° square cuts)
- ❌ Custom-fabricated metal parts
- ❌ Permit (verify with your city — at this size, most residential zones
  don't require a permit for an unoccupied accessory structure, but the
  Maricopa County wind amendments and IRC triggers are real if the structure
  is larger. See `analysis/wind_load_report.md` for the engineering.)

---

## Tools needed

- Circular saw (or have the lumber yard pre-cut)
- Drill / impact driver
- ½" drill bit (for the ½" hinge rod clearance through the bed wall)
- ⅜" drill bit (for carriage bolts)
- ¼" pilot bit (for deck screws)
- Tape measure, square, level
- 9/16" wrench (for 3/8" carriage bolts)
- Socket wrench for lag bolts

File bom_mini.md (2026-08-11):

# Wattplot Mini v2.4 — Bill of Materials

Benchtop design-validation prototype. **18"×14" bed, ECO-WORTHY 10W
panel, 100mm kickstand linear actuator** — sized to match the parts
already ordered for this build.

Build before committing to the full-size build to validate:
- Real solar charging (10W panel → MPPT → battery)
- 100mm kickstand actuator geometry (compression, low-side mount, 0-35°)
- 1x2 frame structural behavior
- Same firmware / sensors / MPPT / wiring as the full-size
- Smart planter: soil moisture, 3× DS18B20 temps, tap-water solenoid, energy + SOC + POA monitoring

**Total cost: ~$130-170. Total build time: ~3-4 hours.**

Same design rules as the full-size build (`bom.md`):
1. **No miter cuts** — every cut is a 90° square cut.
2. **All hardware off the shelf** — Home Depot, Amazon, McMaster.
3. **Simple, common dimensions** — all from 8ft stock, 1x2 / 1x4 / 2x4 PT DF.

---

## Tilt range: 0-35° (kickstand-limited)

The kickstand actuator geometry limits the panel to **0-35° tilt** (not
the full 0-90°). For a 10W trickle-charger panel, this is fine — the
panel produces 17 kWh/yr at 0° flat or 15.9 kWh/yr at 35° (the
power-optimal tilt for Phoenix in summer). 0-35° covers the full useful
range for a small panel.

The full-size Wattplot keeps its 24" stroke linear actuator for full
0-90° range (snow shedding, high-wind survival, max winter DLI). The
mini doesn't need that.

---

## Lumber (PT Douglas Fir)

### Bed walls (1x4 PT DF, actual 0.75" × 3.5")
| Qty | Size | Length | Use | Source / waste |
|---|---|---|---|---|
| 2 | 1x4 | 18" | Long walls (N and S), half-lap corners | 1x4x8ft, 60" waste per board |
| 2 | 1x4 | 12.5" | Short walls (E and W), half-lap corners | 1x4x8ft, 4 short walls from 1 board (25" used, 71" waste) |

**Lumber for bed walls: 1 board, ~3 bf** (both long walls + 2 short walls from 1x4x8ft)

### Frame rails (1x2 PT DF, actual 0.75" × 1.5")
| Qty | Size | Length | Use | Source / waste |
|---|---|---|---|---|
| 2 | 1x2 | 18" | Long rails (E and W sides of panel) | 1x2x8ft, 60" waste per board |
| 2 | 1x2 | 12.5" | Cross rails (N and S ends of panel) | 1x2x8ft, 4 cross rails from 1 board (25" used, 71" waste) |

**Lumber for frame rails: 1 board, ~2 bf** (4 rails from 1x2x8ft, fits all on one board)

### Diagonal brace (2x4 PT DF, actual 1.5" × 3.5")
| Qty | Size | Length | Use | Source / waste |
|---|---|---|---|---|
| 1 | 2x4 | 21" | Diagonal brace, square ends butt into long rails | 2x4x8ft, 75" waste |

**Lumber for brace: 1 board offcut, ~2 bf** (or 2x4 scrap from another project)

### Bed skids (1x2 PT DF, actual 0.75" × 0.75")
| Qty | Size | Length | Use | Source / waste |
|---|---|---|---|---|
| 2 | 1x2 | 18" | Long skids, under the long walls | 1x2x8ft, 60" waste per board (cut 2 from 1 board) |

**Lumber for skids: 1 board, 1 bf** (2 skids from 1x2x8ft)

### Kickstand actuator mount (1x2 PT DF, scraps)
| Qty | Size | Length | Use | Source / waste |
|---|---|---|---|---|
| 1 | 1x2 | 3" | Bottom mount block, on bed's south wall | 1x2 offcut |
| 1 | 1x2 | 3" | Top mount bracket, hanging below panel | 1x2 offcut |

**Lumber for kickstand mount: offcuts, ~0 bf** (use scraps from the rails/skids boards)

### Total lumber

| Material | Boards | Cost |
|---|---|---|
| 1x4x8ft (1 board) | 1 | ~$5 |
| 1x2x8ft (2 boards: 1 for frame, 1 for skids) | 2 | ~$7 |
| 2x4x8ft (1 board offcut for brace) | 1 | ~$7 |
| **Total lumber** | **4 boards** | **~$19** |

---

## Hardware (all off the shelf)

### Hinges + continuous hinge pin
| Qty | Item | Source | Cost |
|---|---|---|---|
| 2 | 1.5" butt hinge, ⅜" pin (galvanized) | Home Depot | ~$3 ea = **$6** |
| 1 | ⅜" × 22" steel rod (continuous hinge pin) | Home Depot | **$3** |

### Panel + mounting
| Qty | Item | Source | Cost |
|---|---|---|---|
| 1 | ECO-WORTHY 10W 12V solar panel, 13.3" × 8.1" × 0.7" (1.88 lb) | Amazon | **$25** (already ordered) |
| 4 | 1" aluminum mid-clamps, 18mm channel, M8 bolt | Amazon | ~$2 ea = **$8** |

### Kickstand actuator + clevis pins
| Qty | Item | Source | Cost |
|---|---|---|---|
| 1 | 100mm (3.94") stroke 12V linear actuator, 70N (15.7 lbf) | Amazon | **$15** (already ordered) |
| 2 | ⅜" clevis pins + cotter pins | Hardware store | **$2** |

### Fasteners
| Qty | Item | Use |
|---|---|---|
| 16 | #6 × 1.5" wood screws (HDG) | Bed half-lap corners, frame corners |
| 8 | #6 × 1" wood screws | Diagonal brace to frame |
| 4 | M8 × 1.5" stainless bolts + EPDM washers | Mid-clamps to rails |
| 8 | 5/64" × 1" wood screws | Hinge leaves to bed wall and frame rail |
| 4 | #6 × 1.5" wood screws | Kickstand mount blocks |
| 2 | ⅜" × 3" clevis pins + cotter pins | Actuator clevis to mount blocks |

**Total fasteners: ~$8**

### Electronics (same as full-size, breadboard build)

The mini uses the **same schematic rev B controller** as the full-size, but
on a breadboard / perfboard instead of a custom PCB. Components grouped
by **subsystem** so you know what each part is for. See `docs/schematic.html`
for the full schematic and `bom.md` (full-size) for the PCB build of these.

#### Power tree (battery → 5 V → 3.3 V)
| Qty | Item | Source | Cost |
|---|---|---|---|
| 1 | **Sunapex 10A MPPT charge controller** (10 A, 12 V, MPPT, IP67, LiFePO4-aware, SAE connectors) | Amazon | **$25** (need to order) |
| 1 | 12V 7Ah LiFePO4 battery (with BMS) | Amazon | **$25** (already ordered) |
| 1 | 5 V buck module (MP1584 or equiv) | Amazon | ~$3 |
| 1 | 3.3 V LDO module (AMS1117 or equiv) | Amazon | ~$1 |

#### MCU / Controller
| Qty | Item | Source | Cost |
|---|---|---|---|
| 1 | ESP32-S3-DevKitC-1-N16R8 (matches full-size schematic rev B) | Mouser / Digi-Key | ~$10 |
| 1 | USB-C cable (for ESP32 programming) | Amazon | **$3** |

#### Actuator (panel tilt)
| Qty | Item | Source | Cost |
|---|---|---|---|
| 1 | 100 mm 12 V kickstand linear actuator (rated for the panel weight) | Amazon / AliExpress | **$12** (already ordered) |
| 1 | DRV8871 breakout board (U5a role) | Amazon / Pololu | ~$5 |
| 1 | 0.1 Ω current-sense shunt (for IPROPI) | Digi-Key | <$1 |

#### Solenoid (water / latch)
| Qty | Item | Source | Cost |
|---|---|---|---|
| 1 | 12 V solenoid valve, ¼" barb, NC | Amazon | **$10-12** (counted in Watering below) |
| 1 | DRV8871 breakout board (U5b role) | Amazon / Pololu | ~$5 |
| 1 | 0.1 Ω current-sense shunt (for IPROPI jam detect) | Digi-Key | <$1 |

#### Sensors
| Qty | Item | Source | Cost |
|---|---|---|---|
| 3 | DS18B20 waterproof temp sensors (panel, soil, battery) | Amazon | **$11** (5-pack) |
| 1 | 4.7 kΩ pull-up (1-Wire bus) | Amazon | <$1 |
| 1 | Capacitive soil moisture sensor V1.2 (5-pack for spares) | Amazon | **$9** |
| 2 | INA219 current sensor breakout (I²C, addresses 0x40 + 0x41) — matches full-size, gives both panel V/I and actuator bus current. One is enough for battery, but the second is $2 and worth the diagnostic visibility. | Mouser | **$4** |
| 1 | MPU6050 IMU breakout (panel angle, optional) — **NOT BMI160.** ESPHome 2026.7.2 dropped bmi160 from the YAML schema (see ADR-003). MPU6050 is the drop-in replacement at the same I²C footprint. | Mouser | **$2** |

#### Prototyping hardware
| Qty | Item | Source | Cost |
|---|---|---|---|
| 1 | Breadboard or perfboard | Amazon | **$5** |
| ~30 | Jumper wires (M-F, M-M, F-F) | Amazon | **$3** |

**Total electronics (subsystems): ~$118 new + $50 already ordered = $168**

### Watering system (v2.4 — solenoid on tap water)

| Qty | Item | Source | Cost |
|---|---|---|---|
| 1 | 12V DC normally-closed solenoid valve, 1/4" barb, ~2 GPM | Amazon | **$10-12** |
| 1 | 1/4" cold-water tee fitting (brass, for tap line) | Home Depot | **$3** |
| 1 | Pressure regulator 5-30 PSI, 1/4" NPT (optional, recommended) | Amazon | **$10** |
| 10 ft | 1/4" vinyl tubing (food-safe, for drip line) | Amazon | **$8** |
| 1 | Pressure-compensating drip emitter (2 GPH) — pack of 5; bed is 18"×14" so 2-3 emitters is plenty, the rest are spares | Amazon | **$5** |
| 2 | 1/4" tubing barb fittings (for solenoid inlet/outlet) | Amazon | **$3** |
| 4 | Zip ties (for securing tubing) | Home Depot | **$2** |

> **Solenoid driver note:** The solenoid is driven by the **DRV8871
> U5b breakout** listed in the **Solenoid (water / latch)** electronics
> section above — *not* by a separate relay. The v2.4 mini and the v3
> full-size use the same firmware (`firmware/wattplot.yaml`), which
> drives the solenoid through `solenoid_in1_out` / `solenoid_in2_out`
> with brake/coast semantics, nFAULT feedback on GPIO13, and IPROPI
> jam detection. A single-GPIO relay would have required forking the
> firmware — not worth $4 of savings.

**Total watering system: ~$44-48** (similar cost, no reservoir, no pump priming)

### Logging (v2.5 — MQTT log streaming to file)

**Optional but recommended** — see `docs/logging.md` for setup.

| Qty | Item | Source | Cost |
|---|---|---|---|
| 1 | Mosquitto MQTT broker (runs on your PC) | mosquitto.org (free) | **$0** |

No new hardware on the Wattplot itself — the ESP32 publishes log lines
over WiFi to the Mosquitto broker on your PC, and
`tools/log_subscriber.py` writes them to a rotating `logs/wattplot.log`
file (daily rotation, 30-day retention by default, ~30 MB total).

**Total logging: $0** (just your time to install Mosquitto + pip install paho-mqtt)

---

## Cost summary

| Category | New | Already have | Total |
|---|---|---|---|
| Lumber (4 boards) | $19 | — | $19 |
| Hinges + pin | $9 | — | $9 |
| Panel + clamps | $33 | — | $33 |
| Kickstand actuator + pins | $17 | already ordered | $17 |
| Fasteners | $8 | — | $8 |
| Electronics (MPPT, sensors, drivers, breadboard) | $118 | $50 (battery + ESP32) | $168 |
| Watering system (solenoid + tee + drip) | $42 | — | $42 |
| **Total** | **$246** | **$50** | **~$296** |

**v2.4 adds ~$46 (solenoid watering) on top of v2.2 — full smart planter.**
v2.4 swaps the v2.3 pump + 5-gal bucket for a 12V solenoid on tap water:
cheaper to run, no reservoir to refill, no pump priming, fail-safe closed
when de-energized.

(The full-size build is ~$770-$1,210; the mini v2.4 is ~25-38% of that.)

---

## Critical note: CN3791 → Sunapex swap

The **HiLetgo CN3791 MPPT** in the original parts list is **not compatible**
with the 12V LiFePO4 battery. The CN3791 is a 12V solar → **1S LiPo (3.7V)**
charger, not a 12V → 12V charger.

**Replace with a Sunapex 10A MPPT** ($25, Amazon, search "Sunapex 10A
MPPT solar charge controller"). True MPPT (not PWM), 10 A, 12 V only,
IP67 waterproof, has an explicit LiFePO4 charge mode, SAE connectors
(with polarity reversal adapter), 1-year warranty. **No host connection
needed** — the Sunapex runs its own MPPT and charge profile, the ESP32
only reads the battery voltage. This deletes ~80 lines of UART/MPPT code
from the firmware. The DPS5005 was previously the MPPT path (ESP32
commanded its output voltage over UART), but a real hardware MPPT does
the job better and is weatherproof out of the box.

> Earlier revisions of this BOM (v2.4 first cut) specified a **Solperk
> HC-SM10A** ($35, IP68, 5-yr warranty) instead. The Sunapex is the same
> form factor and spec for $10 less — 1-year warranty vs 5-year, IP67
> vs IP68 (both adequate for outdoor mounting), and SAE connectors
> instead of screw terminals. Both work for the 10 W panel.

---

## What you DON'T need

- ❌ Welder (it's all screwed)
- ❌ Concrete / rebar / post anchors
- ❌ Steel angle iron / Unistrut
- ❌ Miter saw (all cuts are 90° square cuts)
- ❌ Custom-fabricated metal parts
- ❌ Permit (this is a small benchtop prototype)

---

## Tools needed

- Circular saw (or have the lumber yard pre-cut)
- Drill / impact driver
- ⅛" drill bit (for wood screws)
- 5/64" drill bit (for hinge screws)
- M8 hex driver (for mid-clamp bolts)
- Tape measure, square, level
- Wire stripper
- Multimeter
- Soldering iron (for the perfboard, if not using a breadboard)

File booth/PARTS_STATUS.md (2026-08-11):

# Mini v2.4, Parts Status & Build Tracker

**Target:** Working Mini v2.4, fully assembled, on the booth table.
Faire: **Sept 25–27, 2026** (47 days from 2026-08-09).

> **Status as of 2026-08-09 (W3 of 9):** Mini v2.4 build is on the
> bench. Calibrating IMU and running closed-loop tilt tests. Original
> electronics list (below) is kept as a record of what shipped. **The
> controller row was updated to ESP32-S3 in W3** — the v3.2 ESPHome
> firmware dropped C3 support, so anything you build fresh needs the
> S3 DevKitC-1. PCB v3 (a custom carrier that replaces the Sunapex
> + breadboard) is in development, targeting post-faire. The Mini
> stays on the discrete-component path because it's the booth demo
> and it has to work *now*.
>
> **Refreshed 2026-08-09 against `bom_mini.md` v2.5 (post-W3):** IMU
> part corrected (BMI160 → MPU6050), INA219 count corrected (1 → 2),
> 5 V relay line removed (subsumed by the DRV8871 U5b carrier),
> subtotals re-rolled. Build sequence step 6 fixed (no more "relay").
> See `bom_mini.md` for the source of truth.

## On hand / confirmed ordered (per `docs/build_guide_mini.md`)

- [x] 12V 7Ah LiFePO4 battery (with BMS) — installed
- [x] 100mm (3.94") stroke 12V linear actuator, 70N — installed
- [x] ESP32-S3 DevKitC-1 (N16R8) — installed (sub for the original C3)
- [x] ECO-WORTHY 10W 12V solar panel, 13.3" × 8.1" — installed

## Order list (W1–W2, all installed; refreshed 2026-08-09)

> **As of 2026-08-09:** all items below were received in W1–W2 and
> are installed in the bench build, with the following substitutions
> relative to the original order:
>
> - **ESP32-S3 DevKitC-1** in place of the planned ESP32-C3 (W3
>   sub — required by the v3.2 ESPHome firmware)
> - **DRV8871 H-bridge carrier** in place of the 5V relay (W3
>   sub — required for direction-controlled actuator + solenoid;
>   a relay was single-direction and the v3 firmware uses both
>   polarities for current-based homing on the actuator and
>   brake/coast on the solenoid)
> - **MPU6050 IMU** in place of the planned BMI160 (W3 sub — see
>   ADR-003; ESPHome 2026.7.2 dropped bmi160 from the YAML schema)
> - **Second INA219** (W3 sub — one for panel V/I, one for actuator
>   bus; matches the full-size v3 PCB pin map)
> - **DRV8871 H-bridge for the solenoid** in place of the 5V relay
>   (W3 sub — same chip, second instance; firmware uses
>   `solenoid_in1_out` / `solenoid_in2_out` with nFAULT feedback)

| Qty | Item | Source | ~Cost | Why | Status |
|---|---|---|---|---|---|
| 1 | **Sunapex 10A MPPT** charge controller, IP67, LiFePO4-aware | Amazon | $25 | Replaces the CN3791 (incompatible with 12V LiFePO4) | installed |
| 1 | **MPU6050** IMU breakout (was BMI160 in W1 order — see ADR-003) | Mouser | $2 | Tilt feedback (closed loop) | installed (W3 sub) |
| 2 | INA219 current sensor breakout (was 1 in W1 order — I²C 0x40 + 0x41, panel + actuator bus) | Mouser | $4 | Panel V/I + actuator bus current | installed (W3 sub) |
| 3 | DS18B20 waterproof temperature sensor (5-pack) | Amazon | $11 | Panel, soil, battery temp | installed |
| 1 | Capacitive soil moisture sensor V1.2 (5-pack) | Amazon | $9 | Soil water content | installed |
| 1 | Breadboard or perfboard | Amazon | $5 | Wiring | installed (W3 → replaced by PCB v3 prototype once available) |
| 1 | USB-C cable | Amazon | $3 | ESP32 programming | installed |
| 1 | 12V DC normally-closed solenoid valve, 1/4" barb | Amazon | $10 | Watering system | installed |
| 1 | **DRV8871 H-bridge carrier** (U5b role, solenoid driver — replaces the W1 5V relay) | Amazon | $5 | Solenoid IN1/IN2 + nFAULT + IPROPI jam detect | installed (W3 sub) |
| 1 | Pressure regulator 5-30 PSI, 1/4" NPT | Amazon | $10 | Safe drip pressure | installed |
| 10 ft | 1/4" vinyl tubing (food-safe) | Amazon | $8 | Drip line | installed |
| 1 | Pressure-compensating drip emitter, 2 GPH (5-pack; bed is 18"×14" so 2-3 used, rest spares) | Amazon | $5 | Dripper | installed |
| 2 | 1/4" tubing barb fittings | Amazon | $3 | Solenoid connections | installed |
| 1 | 1/4" cold-water tee, brass | Home Depot | $3 | Tap-line tee | installed |
| 4 | Zip ties | Home Depot | $2 | Tubing | installed |
| ~30 | Jumper wires (M-F, M-M, F-F) | Amazon | $3 | Prototyping | installed |
| 1 | 1.5" butt hinges w/ ⅜" pin (2-pack) | Home Depot | $6 | Frame to bed hinge | installed |
| 1 | ⅜" × 22" steel rod (continuous hinge pin) | Home Depot | $3 | Hinge pin | installed |
| 4 | 1" aluminum mid-clamps for 18mm panel channel | Amazon | $8 | Panel mounting | installed |
| 2 | ⅜" clevis pins + cotter pins | Hardware | $2 | Actuator mount | installed |

**Electronics + watering + hardware subtotal: ~$127** (+$3 vs W1 order:
+$2 for the second INA219, +$1 for the relay→DRV8871 swap; the
DRV8871 carrier is $5 vs the W1 5V relay at $3-5)

## Order list — lumber (W1, picked up; refreshed 2026-08-09)

| Qty | Size | Use |
|---|---|---|
| 1 | 1x4x8 ft PT DF | Bed walls (2 long + 2 short) |
| 2 | 1x2x8 ft PT DF | Frame rails (1 board) + skids + kickstand blocks (1 board) |
| 1 | 2x4x8 ft PT DF | Diagonal brace (cut a 21" piece) |

**Lumber subtotal: ~$19**

## Order list — fasteners (W1, picked up)

- 16 × #6 × 1.5" wood screws (HDG), bed + frame
- 8 × #6 × 1" wood screws, diagonal brace + kickstand blocks
- 4 × M8 × 1.5" stainless bolts + EPDM washers, mid-clamps
- 8 × 5/64" × 1" wood screws, hinge leaves (often come with hinges)

## Grand total ordered in W1–W3

**~$154** (plus tax, plus shipping) — $127 (W3 electronics/watering/hardware) + $19 lumber + $8 fasteners. W1 was $151; W3 added $3 (second INA219 + relay→DRV8871 swap).

## Order timing (historical — for the W1 order)

| Today (Jul 23) | Action | Actual |
|---|---|---|
| Tonight | Walk the list above. Cross off what you already have. | done |
| Tomorrow | Place the Amazon + Mouser orders. | done (W1) |
| Tomorrow | Drive to Home Depot for lumber + brass tee + hinges. | done (W1) |
| Sat/Sun | All parts in hand. Begin build. | done (W2 weekend) |
| By end of W2 (Aug 5) | Mini v2.4 assembled, on the table, talking to the laptop. | done (Aug 4) |

## Current phase (W3, 2026-08-09)

- **Build:** assembled, on the bench, talking to the laptop.
- **Tuning:** calibrating IMU, verifying closed-loop tilt against
  the 0–35° range, validating the soil-moisture dry/wet trigger
  thresholds against `docs/test_checklist.md` Phase A.
- **Risk:** the bench MPPT (Sunapex) is a known-good part; the
  DRV8871 swap (W3) needs a current-limit sanity check before
  the 70N actuator is connected for the first time in-circuit.
- **Booth collateral:** cards and poster (W4). One-pager, FAQ,
  demo script in `docs/` are up to date.

## Build sequence (full guide in `docs/build_guide_mini.md`)

1. **Phase 1: Bed**, 1 hour. Cut half-laps, assemble, attach skids.
2. **Phase 2: Frame**, 1 hour. Rectangle + diagonal brace + hinges.
3. **Phase 3: Panel**, 10 min. Mid-clamps.
4. **Phase 4: Kickstand actuator mount**, 20 min. Bottom + top blocks + clevis pins.
5. **Phase 5: Wire the panel**, 30 min. MC4 → Sunapex → battery. Verify MPPT lights up.
6. **Phase 6: Wire the controller**, 1.5 hours. ESP32-S3 + IMU + 2× INA219 + DS18B20 + soil sensor + DRV8871 (actuator U5a) + DRV8871 (solenoid U5b). Same firmware as the full-size — no relay, no separate solenoid driver.
7. **Phase 7: Flash ESPHome**, 30 min. Use `firmware/wattplot.yaml` (see notes below).
8. **Phase 8: Watering system**, 1 hour. Tap → tee → regulator → solenoid → drip emitter.
9. **Phase 9: Fill + plant**, 30 min. Potting mix + 4 seedlings.
10. **Phase 10: Calibrate + test**, 1 hour. Tilt range, current limits, soil dry/wet trigger.

**Total: ~7-8 hours, one weekend.**

## Firmware note

The Mini uses the same `firmware/wattplot.yaml` v3.2 as the full-size
(ESP32-S3-DevKitC-1, GPIO6/7/10/12/16, DRV8871 for the actuator +
solenoid). Verify the pin map against `docs/pinmap.html` before
wiring — the v2.x C3-era pinouts are stale and won't compile. The
Mini's actuator is much lighter (70N vs 330 lbf full-size) and the
IMU offset will be different. The `control_law.md` constants
(I_safe, deadband) need to be re-tuned for the smaller actuator.

A separate `firmware/wattplot_mini.yaml` is on the to-do list for
after the booth if we have time.

## What NOT to do

- **Do not 3D-print any of the brackets.** They are designed to be
  1×2 wood offcuts. The build guide says so. The build cost is $19 of
  lumber, not $80 of PETG.
- **Do not use a different MPPT.** The Sunapex is the spec. Other MPPTs
  in this size class either don't speak LiFePO4 or are PWM (not MPPT).
  Read `bom_mini.md` §"Critical note" before substituting.
- **Do not skip the ½-lap corners on the bed.** Butt joints will
  rack. The 1.5" wide × 0.375" deep notch is the whole reason the
  bed is square.

## Risk register

| Risk | Mitigation |
|---|---|
| Sunapex out of stock | Solperk HC-SM10A is the documented backup (~$35). Same form factor. |
| ECO-WORTHY 10W panel is backordered | Any 10-20W 12V panel works. The build is sized for 13.3"×8.1"; bigger is fine, just changes the mid-clamp count. |
| Lumber yard only has cedar | Cedar is fine for a raised bed, same dimensions, costs ~30% more. Don't use untreated pine. |
| Solenoid leaks on first run | Use a normally-closed (NC) valve, it fails safe (off) when de-energized. |
| ESP32 won't program | Try a different USB-C cable (many are charge-only). Check the driver. Try ESPHome Web Flasher if `esphome run` won't talk. |
| Tilt range is too small | The 100mm actuator gives 0-35°. The full-size is also capped at 0-35° (the 35° cap is wind-load driven, not actuator-stroke driven — see `analysis/wind_load_report.md`). 0-35° covers Phoenix summer DLI needs for both builds. |

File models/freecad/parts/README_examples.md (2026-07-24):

# Lumber library — usage examples

## Before / after

**Before** (current `bed_wall.py` style):
```python
from models.freecad.parts._helpers import box, add_feature
from models.freecad.materials import LUMBER

NOMINAL = "2x12"
T = LUMBER[NOMINAL]["actual_t"]    # 1.5
H = LUMBER[NOMINAL]["actual_h"]    # 11.25
NOTCH_DEPTH = 3.0

def make_bed_long_wall(doc, side="north", name=None):
    wall = box(BED_L, T, H, x=0, y=0, z=0)
    notch = box(NOTCH_DEPTH, H, T / 2.0, x=0, y=0, z=0)
    wall = wall.cut(notch)        # cut +X end
    notch = box(NOTCH_DEPTH, H, T / 2.0, x=BED_L - NOTCH_DEPTH, y=0, z=0)
    wall = wall.cut(notch)        # cut -X end
    return add_feature(doc, name, wall)
```

**After** (with `lumber.py`):
```python
from models.freecad.parts.lumber import make_lumber, cut_end_notch
from models.freecad.parts._helpers import add_feature

def make_bed_long_wall(doc, side="north", name=None):
    wall = make_lumber("2x12", length=BED_L, axis="X", origin=(0, 0, 0))
    wall = cut_end_notch(wall, "2x12", length=3.0,
                         end_offset=0, end_axis="X")                # +X end
    wall = cut_end_notch(wall, "2x12", length=3.0,
                         end_offset=BED_L - 3.0, end_axis="X")      # -X end
    return add_feature(doc, name, wall)
```

The "after" reads like a lumber yard: "a 2x12, 96 inches, with half-lap notches at both ends."

## Common patterns

### Place a 2x6 horizontal at a specific point
```python
from models.freecad.parts.lumber import make_lumber
beam = make_lumber("2x6", length=42, origin=(10, 0, 5))
```

### Vertical post
```python
post = make_lumber("4x4", length=120, axis="Y", origin=(0, 0, 0))
# Now you have a 10-ft post, base at origin, going up the Y axis
```

### A board with one half-lap end
```python
from models.freecad.parts.lumber import make_lumber, cut_end_notch
beam = make_lumber("2x6", length=42)
beam = cut_end_notch(beam, "2x6", length=3.0,
                     end_offset=42 - 3.0, end_axis="X")
```

### Drill a hole through a board
```python
from models.freecad.parts.lumber import make_lumber, make_drilled_hole
import FreeCAD as App

rail = make_lumber("2x6", length=42, origin=(0, 0, 0))
hole = make_drilled_hole(diameter=0.5, axis="Y", through=True)
hole.translate(App.Vector(21, 0, 2.75))   # 21" along X, 2.75" up from bottom
rail = rail.cut(hole)
```

### Full bed corner: 2 long walls + 2 short walls, all with half-laps
```python
from models.freecad.parts.lumber import make_lumber, cut_end_notch
from models.freecad.parts._helpers import add_feature

def make_bed(doc, name="Bed"):
    L, W = 96.0, 44.6
    T_long = make_lumber("2x12", length=L, origin=(0, 0, 0))           # north
    T_long = cut_end_notch(T_long, "2x12", 3.0, 0, "X")
    T_long = cut_end_notch(T_long, "2x12", 3.0, L - 3.0, "X")
    T_short = make_lumber("2x12", length=W, axis="Z", origin=(0, 0, 0))  # west
    T_short = cut_end_notch(T_short, "2x12", 3.0, 0, "Z")
    T_short = cut_end_notch(T_short, "2x12", 3.0, W - 3.0, "Z")
    # ... add east and south walls, position them, fuse or add separately
    return add_feature(doc, name, T_long)
```

## Why this is better than primitives

- **Read like a lumber yard.** `make_lumber("2x6", length=42)` is what you'd
  ask for at Home Depot.
- **Catalog enforced.** `make_lumber("2x5")` raises `ValueError` — there's
  no such lumber. Design rule #3 (simple common dimensions) is automatic.
- **One source of truth for dimensions.** The `LUMBER` dict in `materials.py`
  is the single place dimensions live. The library reads from it.
- **Lazy FreeCAD imports.** The file imports cleanly outside FreeCAD
  (for build calculators, etc.). FreeCAD is only imported when you call a
  function that needs it.
- **Same dimensions as the wind/sun sims.** The wood physics in
  `analysis/wind_load.py` and the panel cuts in `models/freecad/parts/`
  both read from `LUMBER` — no risk of drift.

## Vendor hardware (STEP files)

For hinges, panel clamps, and the linear actuator, the `lumber.py`
library has `load_vendor_part(filename)` that imports a STEP file from
`models/freecad/parts/vendor/`. See `vendor/README.md` for the recommended
files and where to download them.

If a STEP file isn't available, use the parametric helpers
(`make_bolt`, `make_panel_rect`) for a simplified visual representation.

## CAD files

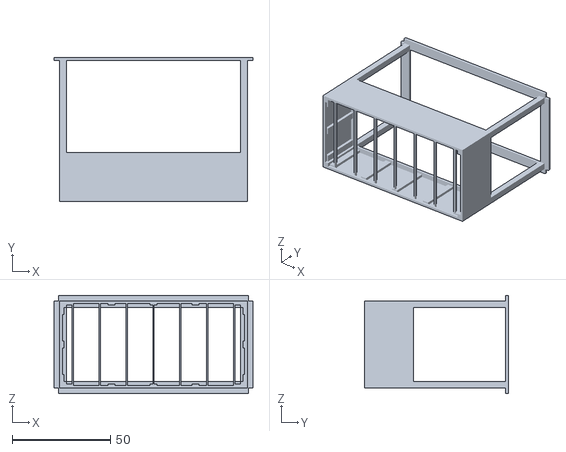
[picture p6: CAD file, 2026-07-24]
booth/wattplot.stl
101.5 x 73.5 x 50.1

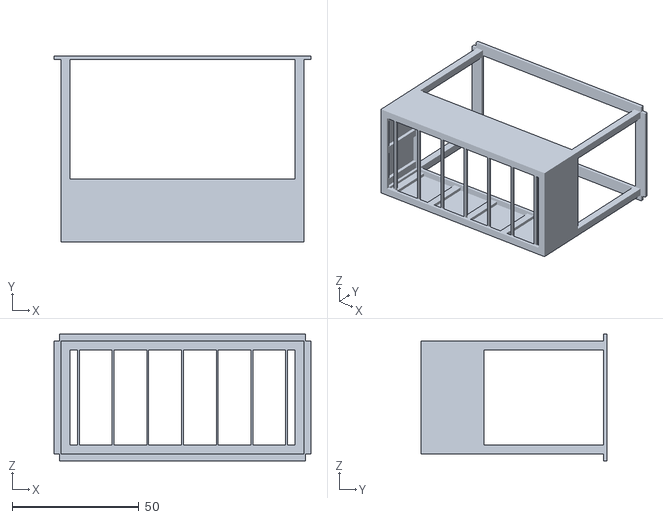
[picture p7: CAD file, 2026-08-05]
docs/booth/wattplot.stl
101.5 x 73.5 x 50.1

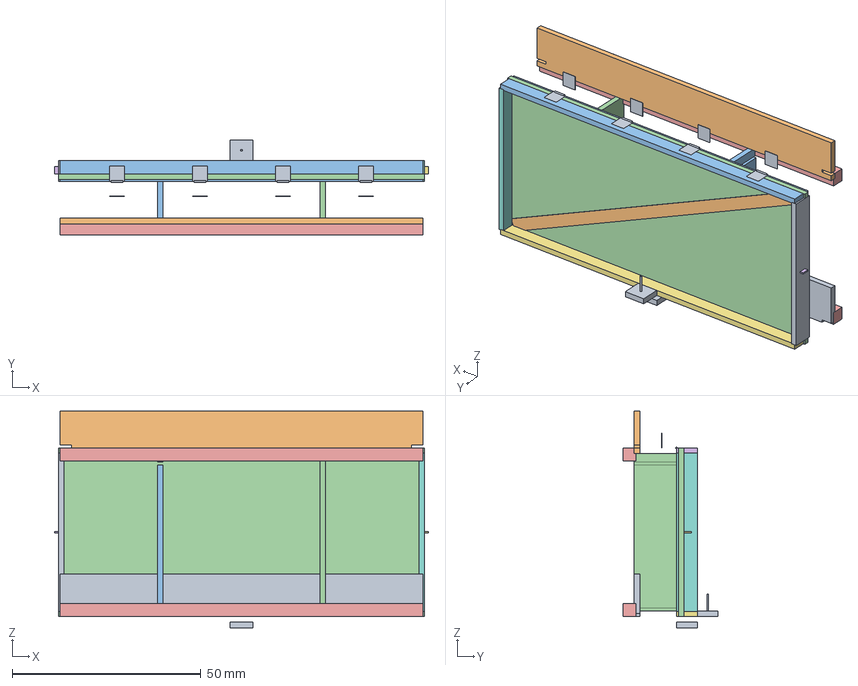
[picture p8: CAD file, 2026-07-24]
models/wattplot_v2_residential_72cell.fcstd
99.0 x 25.2 x 57.3 mm
BedLongWall_north
BedLongWall_south
BedShortWall_west
BedShortWall_east
BedSkids
FrameLongRail_south
FrameLongRail_north
FrameCrossRail_east
FrameCrossRail_west
DiagonalBrace
FrameAssembly
Panel
Hinge__33
Hinge__11
Hinge_11
Hinge_33
HingeSet
Clamp__24__22
Clamp_24__22
Clamp__24_22
Clamp_24_22
Clamp__48_0
Clamp_48_0
PanelClampSet
ActuatorMount

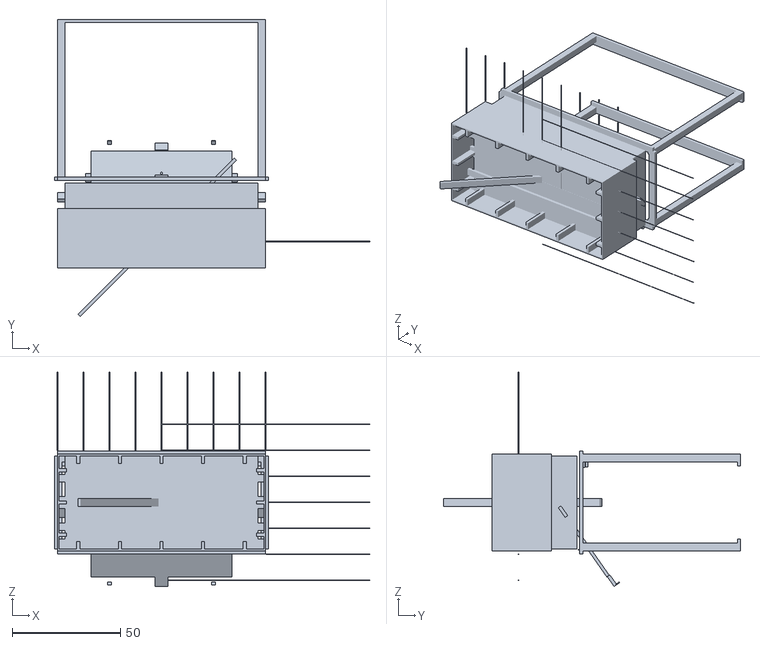
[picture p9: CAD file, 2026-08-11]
renders/wattplot_residential_60cell.stl
145.4 x 137.1 x 98.8

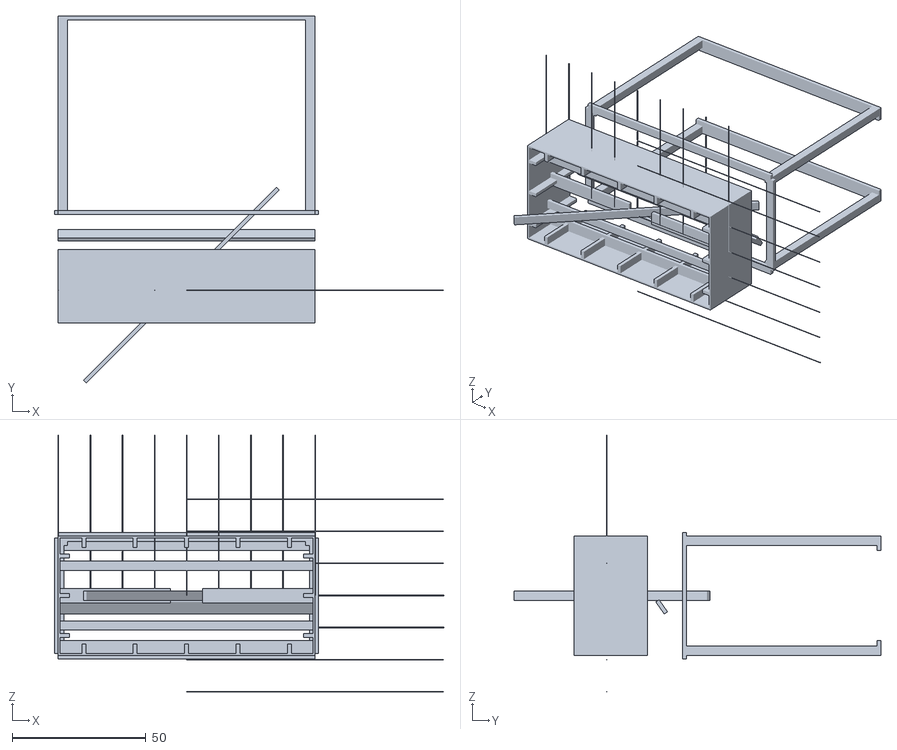
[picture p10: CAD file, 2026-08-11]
renders/wattplot_longi_620W_wood.stl
145.4 x 137.1 x 96.0

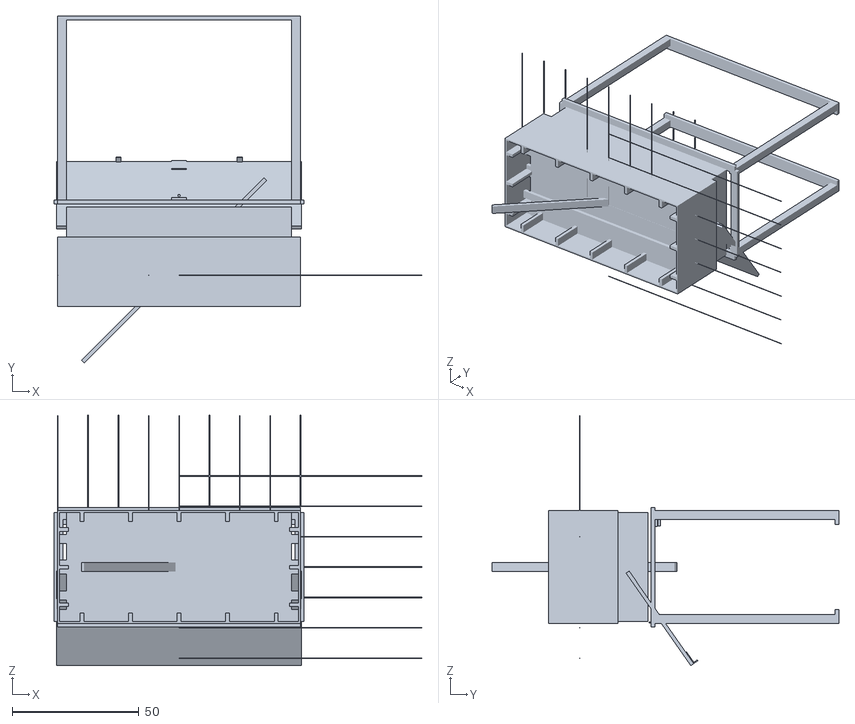
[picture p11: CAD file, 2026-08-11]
renders/wattplot_longi_620W.stl
145.4 x 137.1 x 98.9

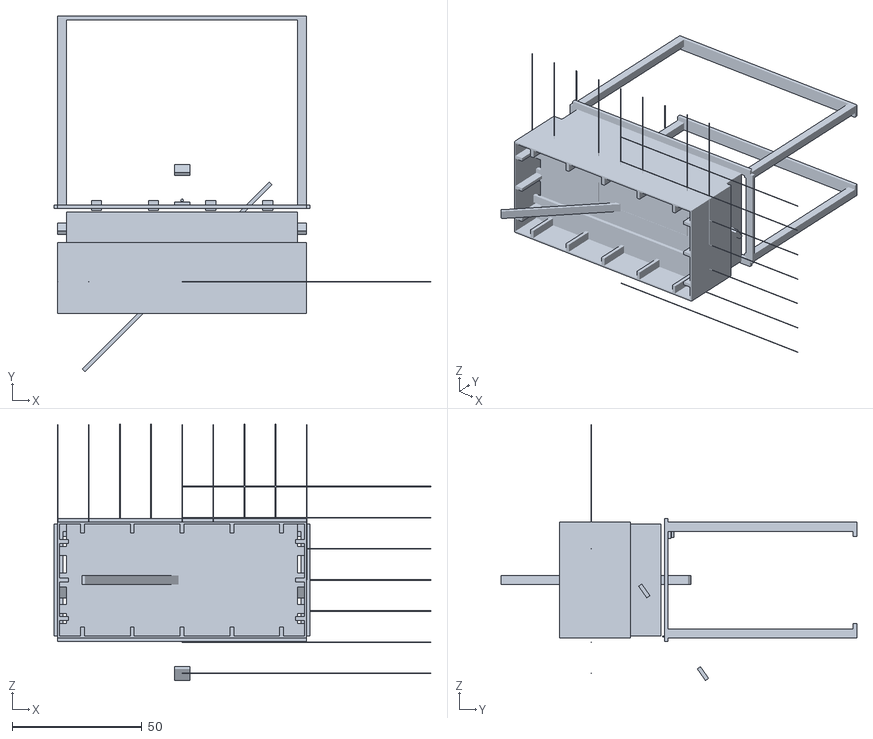
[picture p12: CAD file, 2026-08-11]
renders/wattplot_longi_620W_nopanel.stl
145.4 x 137.1 x 98.8

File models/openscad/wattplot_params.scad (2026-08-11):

// =============================================================================
// wattplot_params.scad -- mirror of wattplot_params.py
// =============================================================================
//
// DO NOT EDIT THESE NUMBERS WITHOUT UPDATING wattplot_params.py AND
// firmware/tests/test_openscad_params.py.
//
// The Python source of truth is wattplot_params.py at the repo root.
// This file is a hand-maintained mirror so the OpenSCAD models can
// render without Python. A CI test (test_openscad_params.py) reads
// both and fails if any number has drifted.
//
// If you change a value here, change it in wattplot_params.py first
// and update the test expectations in test_openscad_params.py. The
// commit message should reference the param name (e.g.
// "scad: bump POSTS.height_in to 78 for v3.1 storm margin").
//
// All dimensions are in inches. OpenSCAD's $fn controls mesh
// resolution -- 64 gives a clean STL that's about 2 MB at this
// model's complexity.

// ---------- LOCATION ----------
location_latitude  = 33.45;     // Phoenix, AZ
location_longitude = -112.07;
location_elevation_m = 337;
location_design_wind_mph = 115.0; // ASCE 7-22, Risk Cat II 700-yr

// ---------- PLANTER LIMITS ----------
max_planter_L_in = 96.0;          // 8 ft stock, no waste on long rails
max_planter_W_in = 60.0;          // 5 ft (8 ft cross-cut, 2 cross-rails per board)

// ---------- BED (planter, ballasted) ----------
bed_outer_L_in       = 96.0;       // 8 ft (capped at max_planter_L_in)
bed_outer_W_in       = 44.6;       // matches panel width
bed_wall_thk_in      = 0.75;       // 1x6 cedar (3/4" actual)
bed_wall_h_in        = 27.5;       // 5 courses of 1x6 (5.5" actual)
                                   //   wind-sized: SF_overturning 2.55 at 35°
bed_soil_fill_in     = 25.5;       // 2" freeboard below the rim
                                   //   ~60 cu ft = 2.2 cu yd = ~4,000 lb
bed_skid_h_in        = 1.5;        // walls rest on 2x4 footers
bed_skid_side_in     = 3.5;        // 4x nominal

// ---------- BED WALL (1x6 cedar skin over 2x4 cleats) ----------
wall_skin_thk_in   = 0.75;
wall_course_h_in   = 5.5;
wall_courses       = 5;            // 5 x 5.5" = 27.5" wall
wall_cleat_thk_in  = 1.5;          // 2x4 actual
wall_cleat_wid_in  = 3.5;          // 2x4 actual
wall_cleats_long   = 5;            // per long wall
wall_cleats_short  = 3;            // per short wall
wall_header_thk_in = 1.5;         // 2x4 on wide face
wall_header_wid_in = 3.5;

// ---------- POSTS (4x4 PT, 72" tall, walk-under canopy) ----------
post_thk_in  = 3.5;               // 4x4 actual
post_height_in = 72.0;            // 6 ft -- walk-under / reach-under
post_count   = 4;
post_rail_thk_in = 1.5;          // 2x6 on post tops
post_rail_wid_in = 5.5;

// ---------- PANEL (LONGi Hi-MO X10 620W default) ----------
panel_L_in        = 97.0;         // 8.08 ft (overhangs bed 0.5"/side)
panel_W_in        = 44.6;         // 3.72 ft
panel_thk_in      = 1.4;
panel_mass_lb     = 65.0;
panel_wattage     = 620;
panel_tilt_deg    = 35.0;         // 0 = flat, 35 = max (wind-limited)

// ---------- CONTROL (tilt cap + PI setpoint) ----------
control_max_tilt_deg  = 35.0;     // STRUCTURAL cap. See ADR-001.
control_target_current_A = 0.5;
control_hard_current_limit_A = 2.5;

// ---------- FRAME (perimeter around the panel) ----------
frame_long_rail_thk_in   = 1.5;    // 2x6 actual
frame_long_rail_wid_in   = 5.5;
frame_long_rail_length_in = 96.0;  // 8 ft stock, no waste

frame_cross_rail_thk_in   = 1.5;   // 2x6 actual
frame_cross_rail_wid_in   = 5.5;
frame_cross_rail_length_in = 42.0; // 2x6x8ft cut to 42"

frame_brace_thk_in   = 1.5;         // 2x4 actual
frame_brace_wid_in   = 3.5;
frame_brace_length_in = 102.0;     // 2x4x10ft cut to 102"

// ---------- HINGES + PANEL CLAMPS ----------
hinge_leaf_in    = 4.0;            // 4"x4" leaf, 1/2" pin
hinge_pin_d_in    = 0.5;
hinge_count      = 4;
hinge_spacing_in = 22.0;           // 22" o.c.
hinge_rod_length_in = 72.0;        // 1/2" x 72" steel rod (HD)

panel_clamp_length_in = 2.0;       // IronRidge mid-clamp, 35mm channel
panel_clamp_height_in = 2.0;
panel_clamp_thk_in   = 0.4;
panel_clamps_per_long_rail  = 2;
panel_clamps_per_cross_rail = 1;

// ---------- ACTUATOR MOUNT ----------
actuator_block_thk_in  = 1.5;      // 2x6 actual
actuator_block_wid_in  = 5.5;
actuator_block_length_in = 6.0;
actuator_stroke_in     = 4.0;       // 12V linear actuator
actuator_width_in      = 2.0;       // body width (for clearance check)
actuator_height_in     = 2.5;

// ---------- DERIVED (don't change) ----------
// Bed is sized so the panel overhangs the rails by 0.5" per side.
// The panel mid-clamps grip the aluminum frame, not the glass.
bed_inner_L_in = bed_outer_L_in - 2 * post_thk_in;
bed_inner_W_in = bed_outer_W_in - 2 * wall_skin_thk_in;
// Wall sits on top of skid; rim = wall + skid.
bed_rim_h_in = bed_wall_h_in + bed_skid_h_in;
// Panel frame offset above the bed rail (clearance for the clamp).
panel_clearance_in = 2.0;         // 2" above the rail top

// Render resolution: $fn controls segment count for curves.
// 64 gives a clean STL ~2 MB. Lower for fast preview, higher for
// 3D printing.
$fn = 64;

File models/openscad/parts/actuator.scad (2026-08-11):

// =============================================================================
// parts/actuator.scad -- the linear actuator + 2 clevis blocks
// =============================================================================
//
// 12V, 4" stroke, 330 lb. Mounted between the bed's north wall (clevis
// block) and the frame's north rail (clevis block). Tilts with the
// frame on the rail side; fixed on the bed side.

include <../wattplot_params.scad>

module actuator_assembly() {
    hinge_y = bed_rim_h_in + 0.5;
    hinge_z = -bed_outer_W_in/2 + 0.5;
    panel_pivot_x = 0;
    // Clevis block on the bed's north wall (fixed -- doesn't tilt)
    color(col_actuator_default)
    translate([0, bed_rim_h_in + 1.0, bed_outer_W_in/2 - wall_skin_thk_in - actuator_block_wid_in/2])
        cube([actuator_block_length_in, actuator_block_thk_in, actuator_block_wid_in], center=true);
    // Clevis block on the frame's north rail (moves with the frame)
    color(col_actuator_default)
    translate([panel_pivot_x, hinge_y, hinge_z])
        rotate([panel_tilt_deg, 0, 0])
        translate([0, panel_clearance_in + 1.0, -bed_outer_W_in/2 + actuator_block_wid_in/2])
            cube([actuator_block_length_in, actuator_block_thk_in, actuator_block_wid_in], center=true);
    // The actuator body itself: visualized as a cylinder between
    // the two clevis blocks. Real actuator is a 12V worm-drive
    // unit; we model it as a cylinder for visual scale only.
    color(col_actuator_default)
    translate([0, bed_rim_h_in + 1.0 + 1.5, bed_outer_W_in/2 - wall_skin_thk_in - actuator_block_wid_in/2 - 0.5])
        rotate([0, 0, 90])
            cylinder(h=actuator_stroke_in, d=1.0, center=true);
}

col_actuator_default = [0.40, 0.40, 0.45];

if (is_undef($use_only)) {
    $fn = 64;
    actuator_assembly();
}

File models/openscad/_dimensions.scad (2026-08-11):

// =============================================================================
// _dimensions.scad -- engineering-drawing dimension lines for the
// technical_drawing.scad output.
// =============================================================================
//
// A small library that draws standard architectural-drawing dim
// lines + arrows + text labels. Use the provided dim_* modules
// from technical_drawing.scad; or build your own at lower level
// with witness_line(), dim_arrow(), dim_text().
//
// Coordinate system: dim_* functions place elements in 2D (the
// projection plane). All units are in inches to match the rest
// of the model.
//
// Default style:
//   - witness lines: 0.02" thick, extend 0.3" beyond the feature
//   - dimension line: 0.02" thick, with arrowheads at each end
//   - text: 0.2" tall, centered above the line
//   - color: black (0, 0, 0); the technical_drawing Starnight
//     colorscheme renders text in a contrast color
//
// Usage:
//   dim_horizontal(start=-48, end=48, y=14, label="96\" bed length");
//   dim_vertical(start=0, end=14, x=-50, label="14\" wall height");
//
// The arrows are small filled triangles, scaled for legibility
// at 2000x1200 image size (the tech drawing's default render).

include <wattplot_params.scad>

// Witness line: a short line from the feature to the dim line.
module witness_line(x1, y1, x2, y2, w=0.02) {
    color([0, 0, 0])
    translate([x1, y1, 0])
        cube([x2 - x1, y2 - y1, w], center=false);
}

// Filled arrowhead at (x, y) pointing in (+x, -x) direction.
// size is the half-length; thickness is 0.05" for legibility.
module arrow_head(x, y, dir, size=0.3, thick=0.04) {
    color([0, 0, 0])
    translate([x, y, 0])
    if (dir > 0) {
        // Arrow pointing in +x direction
        polygon(points=[
            [0, 0],
            [-size, thick/2],
            [-size * 0.7, thick/2],
            [-size * 0.7, -thick/2],
            [-size, -thick/2],
        ]);
    } else {
        // Arrow pointing in -x direction
        polygon(points=[
            [0, 0],
            [size, thick/2],
            [size * 0.7, thick/2],
            [size * 0.7, -thick/2],
            [size, -thick/2],
        ]);
    }
}

// Dimension arrow line with arrowheads at both ends.
// p1 and p2 are [x, y] endpoints.
module dim_arrow(p1, p2, w=0.02) {
    color([0, 0, 0])
    translate([p1[0], p1[1], 0])
        cube([p2[0] - p1[0], p2[1] - p1[1], w], center=false);
    // Arrowheads: at the line's ends, perpendicular to the
    // direction. Compute direction from dx, dy.
    dx = p2[0] - p1[0];
    dy = p2[1] - p1[1];
    L = sqrt(dx*dx + dy*dy);
    if (L > 0) {
        ux = dx / L;
        uy = dy / L;
        size = 0.3;
        thick = 0.04;
        // Arrow at p1 pointing back toward p2
        translate([p1[0], p1[1], 0])
            rotate(atan2(uy, ux) - 90)
                polygon(points=[
                    [size, 0],
                    [-size * 0.7, thick],
                    [-size * 0.7, -thick],
                ]);
        // Arrow at p2 pointing back toward p1
        translate([p2[0], p2[1], 0])
            rotate(atan2(-uy, -ux) - 90)
                polygon(points=[
                    [size, 0],
                    [-size * 0.7, thick],
                    [-size * 0.7, -thick],
                ]);
    }
}

// Dimension text. halign centers above the line; valign=baseline
// means the bottom of the text is on the line.
module dim_text(x, y, label, size=0.35, halign="center", valign="bottom") {
    color([0, 0, 0])
    translate([x, y, 0])
        text(label, size=size, halign=halign, valign=valign, font="Liberation Sans");
}

// Horizontal dimension: two features at (x_start, y_feat) and
// (x_end, y_feat), label centered above the dim line. y_label
// is the y of the text; the dim line sits at y_label - 0.3.
module dim_horizontal(x_start, x_end, y_feat, label, ext=0.4) {
    // Witness lines from each feature down to the dim line.
    y_dim = y_feat - ext;
    witness_line(x_start, y_feat, x_start, y_dim + 0.05);
    witness_line(x_end, y_feat, x_end, y_dim + 0.05);
    // Dim line
    dim_arrow([x_start, y_dim], [x_end, y_dim]);
    // Text above the line
    dim_text((x_start + x_end) / 2, y_dim + 0.3, label);
}

// Vertical dimension: features at (x_feat, y_start) and
// (x_feat, y_end).
module dim_vertical(x_feat, y_start, y_end, label, ext=0.4) {
    x_dim = x_feat - ext;
    witness_line(x_feat, y_start, x_dim + 0.05, y_start);
    witness_line(x_feat, y_end, x_dim + 0.05, y_end);
    dim_arrow([x_dim, y_start], [x_dim, y_end]);
    dim_text(x_dim - 0.3, (y_start + y_end) / 2, label, halign="right", valign="center");
}

// Arc for showing the panel tilt angle.
module dim_angle_arc(cx, cy, radius, start_deg, end_deg) {
    steps = 16;
    step_deg = (end_deg - start_deg) / steps;
    color([0, 0, 0])
    for (i = [0:steps-1]) {
        a1 = start_deg + i * step_deg;
        a2 = a1 + step_deg;
        p1 = [cx + radius * cos(a1), cy + radius * sin(a1)];
        p2 = [cx + radius * cos(a2), cy + radius * sin(a2)];
        translate([p1[0], p1[1], 0])
            cube([p2[0] - p1[0], p2[1] - p1[1], 0.02], center=false);
    }
}

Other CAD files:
models/wattplot_v2.fcstd
renders/wattplot_residential_72cell.stl
renders/wattplot_large_format_1m65.stl
renders/wattplot_commercial_96cell.stl
models/openscad/technical_drawing.scad
models/openscad/parts/_palette.scad
models/openscad/parts/bed.scad
models/openscad/parts/frame.scad
models/openscad/parts/hinges.scad
models/openscad/parts/panel.scad
models/openscad/parts/posts.scad
models/openscad/presets/commercial_96cell.scad
models/openscad/presets/large_format_1m65.scad
models/openscad/presets/longi_620W.scad
models/openscad/presets/residential_60cell.scad
models/openscad/presets/residential_72cell.scad
models/openscad/wattplot.scad

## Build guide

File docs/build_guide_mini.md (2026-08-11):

# Wattplot Mini v2.4 — Physical Build Guide

> **This guide covers the physical build only — Phases 1–4 below
> (bed, frame, panel, kickstand).** The Mini's *electronics* moved on
> with the v3.2 firmware (ESP32-C3 → ESP32-S3, 5V relay → DRV8871
> H-bridge, GPIO retuned). The electronics steps that used to live in
> this file are now in the canonical references listed at the end.
>
> **Why the split:** the physical assembly hasn't changed in three
> revs; the wiring has. Keeping them in one file meant every firmware
> bump had to also update this build guide. Easier to keep the wood
> separate from the wires.

Benchtop design-validation prototype. **18"×14" bed, ECO-WORTHY
10W panel, 100mm kickstand linear actuator**.

**Tilt range:** 0–35° (limited by the kickstand geometry; matches the
power-optimal range per the Phoenix sun sim).

**Build time:** ~3–4 hours (physical only — add ~2 hours for
electronics per the canonical references at the end).

**Build cost (physical only):** ~$42 (lumber + hinges + clamps +
fasteners). Add ~$151 for the electronics — see
[`booth/PARTS_STATUS.md`](../booth/PARTS_STATUS.md) for the full,
up-to-date order list.

**Lumber (all PT DF, all from 8 ft stock):**

- 1 × 1×4×8 ft (bed walls: 2 long + 2 short, all from 1 board)
- 2 × 1×2×8 ft (1 for frame rails, 1 for skids + kickstand mount blocks)
- 1 × 2×4×8 ft (diagonal brace offcut)

**Fasteners:** 16 × #6 × 1.5" wood screws, 8 × #6 × 1" screws,
4 × M8 × 1.5" stainless bolts, 8 × 5/64" × 1" hinge screws,
2 × ⅜" clevis pins. (Full list in [`booth/PARTS_STATUS.md`](../booth/PARTS_STATUS.md).)

---

## Phase 1: Bed (Day 1, ~1 hour)

### 1.1 Cut the half-lap notches

Each bed wall has a 1.5" wide × 0.375" deep notch at each end.

**Tools:** circular saw, chisel, mallet, square

**Process:**
1. Mark the notch location on each wall (1.5" from each end, 0.375" deep).
2. Make multiple passes with the circular saw at the notch depth
   (don't try to cut 0.375" deep in one pass).
3. Clean out the waste with a chisel.
4. Test-fit two walls at a corner.

**Verification:** the two walls meet at a 90° corner with no daylight.

### 1.2 Assemble the bed box

**Tools:** drill, ⅛" pilot bit, #6 × 1.5" wood screws, square

The bed is small (18"×14"), so the joints don't need to be as beefy as
the full-size. Use #6 × 1.5" wood screws (instead of #8 × 2" for the
bigger builds).

**Process:**
1. Lay out the 4 walls on a flat surface.
2. Bring the corners together. The half-lap notches interlock.
3. Pre-drill 2 holes per corner (one near the top, one near the bottom).
4. Drive #6 × 1.5" wood screws through the corners.

**Verification:** bed box is 18" × 14" outside, square (measure
diagonally — both diagonals should be the same length).

### 1.3 Attach the skids

**Tools:** drill, ⅛" pilot bit, #6 × 1.5" screws

**Process:**
1. Flip the bed upside down.
2. Place two 1x2x18" skids under the bed, aligned with the long walls.
3. Pre-drill and screw through the skids into the bed walls.
4. Use 2-3 screws per skid.

**Verification:** skids are flush with the bed ends, square, and the
whole bed sits level on the ground.

---

## Phase 2: Frame (Day 1, ~1 hour)

### 2.1 Assemble the frame rectangle

**Tools:** drill, ⅛" pilot bit, #6 × 1.5" wood screws, square

**Process:**
1. Lay the 4 frame rails (2 long + 2 cross) on a flat surface.
2. The cross rails fit between the long rails. Butt joints (no miter).
3. Pre-drill 2 holes per corner (through the cross rail into the long
   rail end). Use 2 screws per corner.
4. Drive #6 × 1.5" wood screws.

**Verification:** frame is square, 18" × 14" outside, 16.5" × 12.5"
inside.

### 2.2 Add the diagonal brace

**Tools:** drill, ⅛" pilot bit, #6 × 1" screws, measuring tape

**Process:**
1. The 2x4x21" diagonal brace runs corner to corner inside the frame.
2. Position the brace so its ends butt into the inside faces of the
   long rails (square ends, no miter).
3. Pre-drill 2 holes per end (through the brace into the long rail
   inside face).
4. Drive #6 × 1" screws (4 screws total, 2 per end).

**Verification:** brace is at the diagonal angle (~37°), both ends screwed.

### 2.3 Install hinges on the bed's south wall

**Tools:** drill, 5/64" bit (for hinge screws), screws (the small butt
hinges come with their own screws), measuring tape

**Process:**
1. Lay the frame on top of the bed, with the frame's south rail
   resting on the bed's south wall.
2. Position the 2 hinges evenly along the south rail: spacing 13",
   centered (2.5" margin on each end of the 18" rail).
3. Mark the hinge positions on both the frame's south rail and the
   bed's south wall.
4. Pre-drill 4 holes per hinge (2 per leaf), 5/64" bit.
5. Attach the wall leaf to the bed's south wall.
6. Attach the frame leaf to the frame's south rail.
7. The frame should now hinge freely.

**Verification:** frame hinges smoothly between 0° and ~35° tilt. The
⅜" hinge pin holes in both hinges are aligned (the continuous pin
passes through both).

### 2.4 Insert the continuous hinge pin

**Tools:** mallet (rubber), ⅜" drill bit (if pin is too tight)

**Process:**
1. Thread the ⅜" × 22" steel rod through both hinges, starting from
   one end.
2. Tap gently with a rubber mallet to seat the pin fully.
3. The pin should extend ~1" past the last hinge on each end.

**Verification:** pin is fully seated. Frame hinges smoothly with the pin
in place.

---

## Phase 3: Panel (Day 1, ~10 min)

### 3.1 Sizing note (important!)

The 10W panel (13.3" × 8.1") is **smaller** than the frame's interior
(16.5" × 12.5"). The panel sits inside the frame interior with margin
on all four sides:
- Long sides: 1.6" margin per side
- Short sides: 2.2" margin per side

The mid-clamps grip the panel frame at the rail positions, holding the
panel firmly. This is the inverse of the v2.1 design (where the panel
overhung the frame) — for the small 10W panel, it fits comfortably
inside the frame.

### 3.2 Lift the panel onto the frame

**Tools:** hands (10W panel is only 1.88 lb)

**Process:**
1. With the frame flat on the bed, place the 10W panel on top of the
   frame, centered.
2. The panel's aluminum frame should rest on the wood rails.

**Verification:** panel is centered, with even margin on all four sides.

### 3.3 Clamp the panel to the frame

**Tools:** drill, M8 hex driver, 1" mid-clamps

**Process:**
1. Place 2 mid-clamps per long rail (4 total), at positions ±4" from
   the panel center.
2. Tighten the M8 bolts to clamp the panel frame to the wood rails.
3. Torque to ~3 Nm (snug, not crushing — the small panel frame is
   fragile).

**Verification:** panel is firmly attached. Try to wiggle it — should
not move.

### 3.4 Install the kickstand TOP mount bracket

**Tools:** drill, ⅛" pilot bit, #6 × 1.5" wood screws

**Process:**
1. Cut a 3" length of 1x2 (offcut from any 1x2 scrap).
2. Position the bracket on the **underside** of the panel, **2 inches
   north of the south edge** of the panel.
3. The bracket should be flush with the panel's south frame edge (in z
   direction), and sit just below the panel's underside (panel underside
   is at y=4.75, bracket top is at y=4.75, bracket bottom is at y=4.0).
4. **Attach the bracket to the panel's aluminum frame**, not the bed.
   The bracket moves WITH the panel as the panel tilts.
5. Pre-drill 2 holes through the bracket's top face into the panel
   frame's channel.
6. Drive #6 × 1.5" wood screws.

**Verification:** the bracket hangs from the panel's underside, 2"
north of the south edge. The bracket moves up/down as you manually
tilt the panel.

---

## Phase 4: Kickstand Actuator Mount (Day 1, ~20 min)

### 4.1 Mount the bottom block on the bed's south wall

**Tools:** drill, ⅛" pilot bit, #6 × 1.5" wood screws

**Process:**
1. Cut a 3" length of 1x2 (offcut from any 1x2 scrap).
2. Mount the block on the **outer face** of the bed's south wall, at
   the **bottom** (resting on the ground or on the skid).
3. Position: y=0 to 0.75 (ground to top of skid), z=+7 to +7.75
   (outer face of south wall + 1x2 extending out), x=-1.5 to +1.5
   (centered along bed length).
4. Pre-drill 2 holes and drive #6 × 1.5" screws through the block into
   the bed's south wall.

**Verification:** block is firmly attached to the bed's south wall, low.

### 4.2 Insert the bottom pin

**Tools:** ⅜" clevis pin, rubber mallet

**Process:**
1. The bottom pin is a ⅜" × 3.5" steel pin that goes through the
   bottom block, perpendicular to the actuator's axis (i.e., along the
   X axis, parallel to the bed length).
2. Drill a ⅜" hole through the block (centered, 0.375" above the
   block's bottom and 0.75" outside the wall's outer face).
3. Insert the pin through the hole. The pin should extend ~0.25" past
   each side of the block.

**Verification:** pin is in place, sticking out both sides of the block.

### 4.3 Mount the kickstand actuator between the pins

**Tools:** ⅜" clevis pin + cotter pin, rubber mallet

**Process:**
1. The 100mm (3.94") stroke 12V 70N (15.7 lbf) linear actuator has a
   ⅜" clevis pin hole on each end (body side and rod side).
2. Pin the body-side clevis to the **bottom pin** (on the bed's south
   wall, low position).
3. Pin the rod-side clevis to the **top pin** (on the panel's underside
   bracket).
4. Use cotter pins to keep the clevis pins from sliding out.

**Geometry check:** at 0° panel tilt, the actuator is at its **collapsed**
length (~5" between pin centers). When the panel tilts up, the top
pin moves up and inward, and the actuator **extends** by ~0.7" to
reach the 35° tilt position.

**Verification:** actuator is pinned at both ends. Manually extend and
retract the rod — the panel should tilt up and down. Test the range:
- At fully retracted rod, panel should be flat (0°)
- At fully extended rod, panel should be at ~35° tilt

If the panel binds before reaching 35°, the actuator's top bracket
may need to be repositioned. If the actuator doesn't have enough stroke,
you've hit the geometry limit.

---

## Electronics (v3.2 firmware)

The physical build is done. For the controller, sensors, and wiring,
use these canonical references — the wiring chapter in this doc used
to live here, but the firmware has moved on (ESP32-C3 → ESP32-S3, 5V
relay → DRV8871 H-bridge, GPIO retuned) and the wiring has to move
with it.

| Reference | What's in it |
|---|---|
| [`docs/schematic.html`](schematic.html) | Rev B (2026-08-03). 14 sections, 5 V/3.3 V power tree, dual H-bridge. The single source of truth for the controller schematic. |
| [`docs/pinmap.html`](pinmap.html) | Visual diff between the schematic and the firmware. Every wire, every pin, on the ESP32-S3-DevKitC-1. |
| [`docs/wiring.md`](wiring.md) | Cable lengths, AWG, JST pinouts, pre-power checklist. |
| [`docs/sensor_placement.md`](sensor_placement.md) | DS18B20 + capacitive soil + BMI160 placement. Full-size build's guidance applies to the Mini too. |
| [`firmware/README.md`](../firmware/README.md) | Flash + log-stream + MQTT quick-start. The Mini and the full-size use the same firmware. |
| [`firmware/wattplot.yaml`](../firmware/wattplot.yaml) | The YAML itself. The v3.2 revision history is in the header comment. |
| [`booth/PARTS_STATUS.md`](../booth/PARTS_STATUS.md) | The current parts list (W3 2026-08-09), with status of each item. The Mini's electronics list is the source of truth here, not in this build guide. |

### Mini-specific gotchas (read these)

- **Solenoid driver:** the v3.2 firmware uses a **DRV8871 H-bridge**
  (not the 5V relay in the original v2.4 design). The Mini bench
  build has both for transition; the PCB v3 will only have the
  DRV8871.
- **Pin map:** the Mini uses the same ESP32-S3-DevKitC-1 as the
  full-size, so the GPIO map is identical. The Mini's actuator is
  just lighter (70 N vs 330 lbf) — the same control law, the same
  current limit constants.
- **Calibration:** the IMU offset is different (the Mini's panel is
  smaller and tilts less). Re-run the IMU calibration on the Mini's
  panel after mounting; don't carry over the full-size's values.
- **Pre-power checklist:** the [pre-power checklist](pre_build_checklist.md)
  applies. Verify no shorts before applying 12 V.

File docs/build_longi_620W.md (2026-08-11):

# Wattplot Build Guide: longi_620W

Step-by-step assembly of the entire apparatus. Follow the order below. Each step lists the **time**, **tools**, **parts**, and **verification**.

**Total build time:** ~8.7 hr over a weekend (with lumber pre-cut).

**Specifications for this build:**
- Panel: 97.0" × 44.6" × 1.4" (8.08 × 3.72 ft), 65.0 lb
- Wattage: 620 W (0 yr old, bifacial)
- Bed: 96.0" × 44.6" (8.00 × 3.72 ft), 12" deep walls, bottomless

## Phase 0: Pre-build (Day 0, ~1.0 hr)

### 0.1 Lumber (from the cut list)

| Nominal | Qty | Length | Use |
|---|---|---|---|
| 1x6 | 10 | 96.0" (8.00 ft) | long wall skin (N/S), 5 courses |
| 1x6 | 10 | 43.1" (3.59 ft) | short wall skin (W/E), 5 courses |
| 2x4 | 16 | 27.5" (2.29 ft) | wall cleat (vertical, <=24" o.c.) |
| 2x6 | 2 | 96.0" (8.00 ft) | wall cap, hinge + strut walls |
| 2x6 | 2 | 96.0" (8.00 ft) | long frame rail |
| 2x6 | 2 | 41.6" (3.47 ft) | cross frame rail |
| 2x4 | 1 | 105.9" (8.82 ft) | diagonal brace |
| 4x4 | 2 | 96.0" (8.00 ft) | long skid |

**Source from 8-ft stock:** 15× 1x6, 6× 2x4, 5× 2x6, 2× 4x4
**Source from 10-ft stock:** 1× 2x4

**Tip:** many yards will cut to length for free or a small fee. Have them cut each piece on the list above. None of the cuts are mitered (90° square cut only).

### 0.2 Hardware

- 4 × galvanized butt hinge, 4.0"×4.0" leaf, 0.5" pin, HDG
- 1 × ½" × 98.0" steel rod (continuous, through all hinges)
- 6 × aluminum mid-clamps, 35mm channel, M8 SS bolt + EPDM washer
- 8 × 3/8" × 4" carriage bolt HDG + washer + hex nut (bed corner joints)
- 16 × 5/16" × 3" lag bolt HDG (hinge leaf to bed wall)
- 18 × ¼" × 3" deck screw HDG Torx T-25
- 1 × 12V linear actuator, 4.0" stroke, IP65

### 0.3 Panel + electrical

- 1 × **620 W new panel** (from manufacturer)
- 1 × MPPT charge controller (sized to your panel, see `bring_your_own_panel.py`)
- 1 × 12V 100Ah LiFePO4 battery (LiTime or similar)
- 1 × Microinverter (Enphase IQ7+ or APsystems DS3)
- 1 × ESP32-WROOM-32E dev board (or use the PCB from `docs/pcb_design.md`)

## Phase 1: Bed (Day 1, ~2.1 hr)

### 1.1 Cut the wall half-lap notches

Each bed wall has a 3" wide × 0.75" deep notch at each end.

**Tools:** circular saw, chisel, mallet, square

**Process:**
1. Mark the notch location on each wall (3" from each end, 0.75" deep).
2. Make multiple passes with the circular saw at the notch depth.
3. Clean out the waste with a chisel.
4. Test-fit two walls at a corner.

**Verification:** the two walls meet at a 90° corner with no daylight.

### 1.2 Assemble the bed box

**Tools:** drill, ⅛" pilot bit, #6 × 1.5" wood screws, square

**Process:**
1. Lay out the 4 walls on a flat surface. Long walls are 96.0" (8.00 ft). Short walls are 41.6" (3.47 ft).
2. Bring the corners together. The half-lap notches interlock.
3. Pre-drill 2 holes per corner (one near the top, one near the bottom).
4. Drive #6 × 1.5" wood screws through the corners.

**Verification:** bed box is 96.0" × 44.6" outside, square (measure diagonally, both should be the same).

### 1.3 Attach the skids

**Tools:** drill, ⅛" pilot bit, #6 × 1.5" screws

**Process:**
1. Flip the bed upside down.
2. Place two 4x4×96.0" skids under the bed, aligned with the long walls.
3. Pre-drill and screw through the skids into the bed walls.
4. Use 2-3 screws per skid.

**Verification:** skids are flush with the bed ends, square, and the whole bed sits level on the ground.

## Phase 2: Frame (Day 1, ~1.4 hr)

### 2.1 Assemble the frame rectangle

**Tools:** drill, ⅛" pilot bit, #6 × 1.5" wood screws, square

**Process:**
1. Lay the 4 frame rails on a flat surface. Long rails are 96.0" (8.00 ft). Cross rails are 41.6" (3.47 ft).
2. The cross rails fit between the long rails. Butt joints (no miter).
3. Pre-drill 2 holes per corner. Drive #6 × 1.5" wood screws.

**Verification:** frame is 96.0" × 44.6" outside, square.

### 2.2 Add the diagonal brace

**Tools:** drill, ⅛" pilot bit, #6 × 1" screws, measuring tape

**Process:**
1. The 2x4×105.9" diagonal brace runs corner to corner inside the frame.
2. Position the brace so its ends butt into the inside faces of the long rails.
3. Pre-drill 2 holes per end. Drive #6 × 1" screws (4 total).

**Verification:** brace is at the diagonal angle, both ends screwed.

## Phase 3: Hinges (Day 1, ~40 min)

### 3.1 Install hinges on the bed's south wall

**Tools:** drill, 5/64" bit, hinge screws (included with hinges), tape measure

**Process:**
1. Lay the frame on top of the bed, with the frame's south rail resting on the bed's south wall.
2. Position the 4 hinges evenly along the south rail. Spacing: 29.3" center-to-center, with 4" margin on each end.
3. Mark the hinge positions on both the frame's south rail and the bed's south wall.
4. Pre-drill 4 holes per hinge (2 per leaf), 5/64" bit.
5. Attach the wall leaf to the bed's south wall.
6. Attach the frame leaf to the frame's south rail.

**Verification:** frame hinges freely between 0° and ~90° tilt.

### 3.2 Insert the continuous hinge pin

**Tools:** mallet (rubber)

**Process:**
1. Thread the ½" × 98.0" steel rod through all hinges, starting from one end.
2. Tap gently with a rubber mallet to seat the pin fully.
3. The pin should extend ~1" past the last hinge on each end.

**Verification:** pin is fully seated. Frame hinges smoothly with the pin in place.

## Phase 4: Panel (Day 1, ~11 min)

### 4.1 Place the panel on the frame

**Tools:** hands (the panel weighs 65.0 lb).

**Process:**
1. With the frame flat on the bed, place the panel on top of the frame, centered.
2. The panel should rest on the wood rails with even margin on all four sides.

**Verification:** panel is centered, no overhang on the long rails.

### 4.2 Clamp the panel to the frame

**Tools:** drill, M8 hex driver, mid-clamps

**Process:**
1. Place 4 mid-clamps on each long rail (8 total, evenly spaced along the panel frame).
2. Place 2 mid-clamps on each cross rail.
3. Tighten the M8 bolts to clamp the panel frame to the wood rails.
4. Torque to ~3 Nm (snug, not crushing).

**Verification:** panel is firmly attached. Try to wiggle it: should not move.

## Phase 5: Actuator Mount (Day 1, ~20 min)

### 5.1 Mount the bottom block on the bed's north wall

**Tools:** drill, ⅛" pilot bit, #6 × 1.5" wood screws

**Process:**
1. Cut a 3" length of 2x6 (offcut from any 2x6 scrap).
2. Mount the block on the outer face of the bed's north wall, at the bottom.
3. Centered along the bed length.
4. Pre-drill 2 holes and drive #6 × 1.5" screws.

### 5.2 Mount the top bracket on the panel's underside

1. Cut a 3" length of 2x6 (offcut).
2. Mount on the **underside** of the panel, 2" north of the panel's south edge.
3. The bracket should sit just below the panel's underside, flush with the panel's south frame edge.
4. Pre-drill and drive #6 × 1.5" wood screws through the bracket into the panel frame.

### 5.3 Connect the actuator

1. Use ⅜" clevis pins to attach the actuator to both mount blocks.
2. Test manually: the panel should now move from 0° to ~90° (or your actuator's stroke limit).

## Phase 6: Wire the panel to MPPT (Day 2, ~30 min)

### 6.1 MC4 connectors

**Tools:** MC4 crimper, wire stripper, multimeter

**Process:**
1. Crimp MC4 connectors on the panel's PV+ and PV- leads.
2. Plug into the MPPT's PV input (MC4 or SAE adapter, depending on the MPPT).
3. **Verify polarity**: red → +PV, black → -PV. Reverse polarity kills MPPT.

### 6.2 MPPT to battery

1. Connect MPPT battery output to the 12V LiFePO4 battery (via ring terminals or Anderson).
2. Set the MPPT's battery chemistry to LiFePO4 (MODE button on Sunapex).
3. The MPPT status LED should turn on (green = charging or float).

**Verification:** under sun, panel Voc on multimeter matches nameplate ±5%. Battery voltage rises over the next hour.

## Phase 7: Wire the controller (Day 2, ~1.0 hr)

### 7.1 ESP32 + sensors

**Tools:** soldering iron (or perfboard), wire stripper, multimeter

**Pins (from `firmware/wattplot.yaml`):**

| GPIO | Function |
|---|---|
| 4 | DS18B20 1-Wire data |
| 5 | Watering solenoid |
| 16, 17, 18 | H-bridge IN1, IN2, EN |
| 19 | Grow light relay |
| 21, 22 | I2C SDA, SCL |
| 25 | WS2812B status LED |
| 32 | Soil moisture ADC |
| 33 | Battery voltage ADC |
| 34, 35 | Limit switches (0° and 90°) |

### 7.2 Power

1. Connect the DRV8871 H-bridge to the 12V battery (via a 5A fuse).
2. Connect the ESP32's VIN to a 5V buck converter on the 12V rail.
3. Verify all grounds are common.

### 7.3 IMU + INA219 + DS18B20

1. Mount the BMI160 on the panel (under the north rail). I2C address 0x68.
2. Mount the INA219 in series with the actuator (high side). I2C address 0x40.
3. Mount the DS18B20 in the bed soil.
4. All sensors share the I2C bus: SDA (GPIO 21), SCL (GPIO 22), 3.3V, GND.

**Verification:** ESPHome logs show all sensors reporting values.

## Phase 8: Flash ESPHome (Day 2, ~30 min)

### 8.1 First flash over USB

```bash
# Install ESPHome (if not already)
pip install esphome

# Flash the firmware
esphome run firmware/wattplot.yaml
```

### 8.2 WiFi + Home Assistant (optional)

1. Set WiFi credentials in `firmware/secrets.yaml`.
2. Re-flash. ESP32 connects to WiFi and exposes all entities to Home Assistant.
3. Add the ESPHome integration in HA. Entities appear automatically.

## Phase 9: Calibrate + test (Day 2, ~1.0 hr)

### 9.1 IMU zero-tilt offset

1. With the panel flat (0°), read the BMI160's pitch value via ESPHome log.
2. That reading is your zero-tilt offset. Subtract it in the firmware.
3. Re-flash.

### 9.2 Motor current calibration

1. Manually drive the panel to 35°. Read the INA219 current (idle, no wind).
2. Set that as the `target_current_A` in `firmware/wattplot.yaml`.
3. Set `I_safe_A` just above the stall current (typically 2.5A for DRV8871).

### 9.3 Limit switches

1. Drive the panel to 0° (limit switch 0). Adjust switch position so it trips cleanly.
2. Drive to 90° (limit switch 1). Same.
3. Verify the firmware auto-stops at both limits.

### 9.4 End-to-end test

1. Open Home Assistant. Verify all sensors reporting.
2. Trigger a manual tilt from HA. Verify panel moves.
3. Press the user-override button. Verify it overrides the decision stack.
4. Leave it running for 24 hours. Check logs for any errors.

---

**Total time:** ~8.7 hr (with pre-cut lumber and a clean workspace).

**Total cost:** see `python bring_your_own_panel.py` for an itemized estimate.

**Next:** see `docs/test_checklist.md` for per-component and per-system tests.

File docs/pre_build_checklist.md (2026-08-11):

# Pre-build lumber quality checklist

Before you cut any wood, walk through this checklist with the
lumber you've bought. The wind and post-bending analyses assume
**clear, sound lumber** — knots, slope-of-grain, decay, and
wane reduce strength significantly. The NDS values the wind calc
references are for Select Structural grade; most lumber-yard
"construction grade" 4x4 is actually #2 or worse.

If you find any of these issues on the lumber you've bought,
**return it** to the lumber yard and pick different boards. Do not
"work around" it by moving the cut to a different location — the
structural path is well-defined and bad wood on that path means a
real-world failure mode.

## Check every board you plan to use

- [ ] **No knots larger than 1" in the bottom 12" of the four
      4x4 corner posts.** The base of the post carries the
      bending moment (see `analysis/post_bending.py`). A knot at
      that location reduces the cross-section's effective area and
      breaks the SF > 1.5 target.
- [ ] **No knots larger than 1/3 of the board face** anywhere
      along the post or rail length. Smaller knots (>1" but <1/3
      of the face) are acceptable at mid-height where the moment
      is lower.
- [ ] **No through-checks or splits.** A crack running through
      the board face means the fibers are already separated; the
      bending moment will open it further. Tap the board on the
      ground — a dull thud indicates internal decay; a clear
      ring is sound.
- [ ] **No wane (missing wood) on the load-bearing edges.** A
      4x4 with a rounded corner at the bottom is fine for
      appearance but not for a column under a 6 ft lever arm.
- [ ] **No twist > 1/4" over the length of the board.** Check
      by laying it on a flat surface. Twist compounds as the
      frame goes together; > 1/4" twist at the lumber yard is
      > 1" twist in the assembled frame.
- [ ] **No cup > 1/8" over the width.** Cup is OK in the bed skin
      boards (the cleats hold them flat) but not in the rails.
- [ ] **Moisture content < 19%** (KD-19 or kiln-dried). PT
      lumber is usually wetter at delivery. If it's > 19%, let
      it acclimate in the build area for a week or sticker-stack
      it before installing. Wet PT will shrink and open joints
      as it dries.
- [ ] **Stamp check** — the grade stamp should be legible
      ("S-P-F", "Douglas Fir", "Hem-Fir", etc.). If you can't
      read it, the lumber yard can't certify the grade.

## Pressure-treated (PT) specific

- [ ] **Use UC3B or UC4A rated for ground contact.** UC2
      ("above ground") is wrong for the bed cleats and skids.
      The lumber yard should have a tag or stamp. If unsure,
      ask.
- [ ] **Modern ACQ or copper azole treatment, not CCA.** CCA
      (chromated copper arsenate) is banned for residential use
      since 2003 in the US. ACQ is the modern equivalent and
      is what you'll get from Home Depot / Lowe's.
- [ ] **No "checker" surface treatment failures.** PT should
      have a uniform greenish tint and the incising pattern
      should be consistent. Misshapen checker pattern = the
      treatment didn't penetrate uniformly.

## Cedar specific (for the skin boards)

- [ ] **Heartwood > sapwood.** Cedar's rot resistance is in
      the heartwood. Sapwood (the lighter outer ring) will rot
      within 3-5 years when buried. Look for boards with
      mostly heartwood (the darker, aromatic inner wood).
- [ ] **No wane on the face.** Wane on a 1x6 skin board means
      less wood holding the cleat. The cleats are at most
      24" o.c., so any board with wane in the middle 12" of
      its face is unusable.
- [ ] **No "skip" (planer misses).** Cedar is often rough-sawn
      at the lumber yard. Skip is cosmetic for the garden bed
      but matters where the cleat screws bite into the skin.

## Stainless / hot-dip galvanized hardware check

- [ ] **Screws are #10 or larger, ACQ-compatible.** ACQ eats
      plain zinc-coated screws in 6-12 months. Use Simpson
      Strong-Tie Outdoor Accents or equivalent. Box of 1 lb is
      ~$8.
- [ ] **Bolts are hot-dip galvanized or stainless.** The hinge
      bolts, actuator mount, and panel clamps carry significant
      load. Don't use electro-galvanized (zinc-flash) bolts in
      ACQ-treated lumber — they corrode.
- [ ] **No mixing of galvanized and stainless.** Galvanic
      corrosion between dissimilar metals is real; if you use
      stainless bolts in a galvanized bracket, the bracket
      corrodes faster. Pick one metal and stay with it.

## Site prep

- [ ] **Bed footprint level within 1" over 8 ft.** Use a 4 ft
      level + straight edge. The 35° tilt assumption in the
      wind calc is for a level bed; a > 1" tilt in one
      direction adds a moment the calc didn't budget for.
- [ ] **No overhead wires or trees within 10 ft of the
      actuator's max extension.** At 35° tilt the panel + post
      top is ~7.5 ft up. A windstorm that drops a branch on the
      panel will destroy the actuator AND the panel.
- [ ] **Southern exposure, no shade between 10 AM and 4 PM
      year-round.** Use the SunAP (iPhone) or Sun Surveyor (any
      phone) to verify before you commit to the bed location.

## Don't

- [ ] Don't use boards with heart-rot even if it's "small" —
      it grows.
- [ ] Don't use lumber marked "stud grade" for the structural
      members (posts, rails). Stud grade is graded for
      non-structural use; it's not the same as #2 structural.
- [ ] Don't assume "new from lumber yard" = "dry". Most PT is
      wet at delivery; budget for a week of drying time.
- [ ] Don't substitute 2x4 for 4x4 posts — the moment of
      inertia is 8x different (I = bh³/12; 3.5³ vs 1.5³ = 12.7
      ratio). The post-bending analysis assumes 4x4.

## When in doubt

Post-bending analysis (`analysis/post_bending.py`) says the
4×4 fails at 35° unbraced. The two remedies are:
- **Upsize to 6×6** (SF 2.53 with the same loads)
- **Add lateral bracing** (square-cut gusset plates or off-the-shelf
  structural angle brackets)

If your lumber is borderline (knots at the base, lower-grade
stamp), pick one of those remedies. The wind calc is a first-pass
model with a 2.0 SF target; the PE review recommended in the
README is the right move if you have any doubt about the lumber
quality.

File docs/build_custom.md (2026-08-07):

# Wattplot Build Guide: custom

> **STALE — auto-generated from the same template as `build_guide.md`
> (which is itself stale).** The panel-preset-specific geometry (Phase 0
> lumber cut list, Phase 1 bed dimensions) is correct for the "custom"
> preset; the **electronics phases** (Phase 7 onward) reference the v2.4
> architecture that no longer exists. See `firmware/README.md` and
> `docs/pinmap.html` for the current truth. Tracked in
> [ROADMAP.md](../ROADMAP.md).

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

**Total build time:** ~8.7 hr over a weekend (with lumber pre-cut).

**Specifications for this build:**
- Panel: 97.0" × 44.6" × 1.4" (8.08 × 3.72 ft), 62.0 lb
- Wattage: 620 W (0 yr old, monofacial)
- Bed: 96.0" × 45.6" (8.00 × 3.80 ft), 12" deep walls, bottomless

## Phase 0: Pre-build (Day 0, ~1.0 hr)

### 0.1 Lumber (from the cut list)

| Nominal | Qty | Length | Use |
|---|---|---|---|
| 1x6 | 10 | 96.0" (8.00 ft) | long wall skin (N/S), 4 courses |
| 1x6 | 10 | 44.1" (3.68 ft) | short wall skin (W/E), 4 courses |
| 2x4 | 16 | 27.5" (2.29 ft) | wall cleat (vertical, <=24" o.c.) |
| 2x6 | 2 | 96.0" (8.00 ft) | wall cap, hinge + strut walls |
| 2x6 | 2 | 96.0" (8.00 ft) | long frame rail |
| 2x6 | 2 | 42.6" (3.55 ft) | cross frame rail |
| 2x4 | 1 | 106.3" (8.86 ft) | diagonal brace |
| 4x4 | 2 | 96.0" (8.00 ft) | long skid |

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

### 0.2 Hardware

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

### 0.3 Panel + electrical

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

## Phase 1: Bed (Day 1, ~2.1 hr)

### 1.1 Cut the wall half-lap notches

Each bed wall has a 3" wide × 0.75" deep notch at each end.

**Tools:** circular saw, chisel, mallet, square

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

**Verification:** the two walls meet at a 90° corner with no daylight.

### 1.2 Assemble the bed box

**Tools:** drill, ⅛" pilot bit, #6 × 1.5" wood screws, square

**Process:**
1. Lay out the 4 walls on a flat surface. Long walls are 96.0" (8.00 ft). Short walls are 42.6" (3.55 ft).
2. Bring the corners together. The half-lap notches interlock.
3. Pre-drill 2 holes per corner (one near the top, one near the bottom).
4. Drive #6 × 1.5" wood screws through the corners.

**Verification:** bed box is 96.0" × 45.6" outside, square (measure diagonally, both should be the same).

### 1.3 Attach the skids

**Tools:** drill, ⅛" pilot bit, #6 × 1.5" screws

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

## Phase 2: Frame (Day 1, ~1.4 hr)

### 2.1 Assemble the frame rectangle

**Tools:** drill, ⅛" pilot bit, #6 × 1.5" wood screws, square

**Process:**
1. Lay the 4 frame rails on a flat surface. Long rails are 96.0" (8.00 ft). Cross rails are 42.6" (3.55 ft).
2. The cross rails fit between the long rails. Butt joints (no miter).
3. Pre-drill 2 holes per corner. Drive #6 × 1.5" wood screws.

**Verification:** frame is 96.0" × 45.6" outside, square.

### 2.2 Add the diagonal brace

**Tools:** drill, ⅛" pilot bit, #6 × 1" screws, measuring tape

**Process:**
1. The 2x4×106.3" diagonal brace runs corner to corner inside the frame.
2. Position the brace so its ends butt into the inside faces of the long rails.
3. Pre-drill 2 holes per end. Drive #6 × 1" screws (4 total).

**Verification:** brace is at the diagonal angle, both ends screwed.

## Phase 3: Hinges (Day 1, ~40 min)

### 3.1 Install hinges on the bed's south wall

**Tools:** drill, 5/64" bit, hinge screws (included with hinges), tape measure

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

**Verification:** frame hinges freely between 0° and ~90° tilt.

### 3.2 Insert the continuous hinge pin

**Tools:** mallet (rubber)

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

**Verification:** pin is fully seated. Frame hinges smoothly with the pin in place.

## Phase 4: Panel (Day 1, ~11 min)

### 4.1 Place the panel on the frame

**Tools:** hands (the panel weighs 62.0 lb).

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

**Verification:** panel is centered, no overhang on the long rails.

### 4.2 Clamp the panel to the frame

**Tools:** drill, M8 hex driver, mid-clamps

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

**Verification:** panel is firmly attached. Try to wiggle it: should not move.

## Phase 5: Actuator Mount (Day 1, ~20 min)

### 5.1 Mount the bottom block on the bed's north wall

**Tools:** drill, ⅛" pilot bit, #6 × 1.5" wood screws

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

### 5.2 Mount the top bracket on the panel's underside

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

### 5.3 Connect the actuator

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

## Phase 6: Wire the panel to MPPT (Day 2, ~30 min)

### 6.1 MC4 connectors

**Tools:** MC4 crimper, wire stripper, multimeter

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

### 6.2 MPPT to battery

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

## Phase 7: Wire the controller (Day 2, ~1.0 hr)

### 7.1 ESP32 + sensors

**Tools:** soldering iron (or perfboard), wire stripper, multimeter

**Pins (from `firmware/wattplot.yaml`):**

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

### 7.2 Power

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

### 7.3 IMU + INA219 + DS18B20

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

**Verification:** ESPHome logs show all sensors reporting values.

## Phase 8: Flash ESPHome (Day 2, ~30 min)

### 8.1 First flash over USB

```bash
# Install ESPHome (if not already)
pip install esphome

# Flash the firmware
esphome run firmware/wattplot.yaml
```

### 8.2 WiFi + Home Assistant (optional)

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

## Phase 9: Calibrate + test (Day 2, ~1.0 hr)

### 9.1 IMU zero-tilt offset

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

### 9.2 Motor current calibration

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

### 9.3 Limit switches

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

### 9.4 End-to-end test

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

---

**Total time:** ~8.7 hr (with pre-cut lumber and a clean workspace).

**Total cost:** see `python bring_your_own_panel.py` for an itemized estimate.

**Next:** see `docs/test_checklist.md` for per-component and per-system tests.

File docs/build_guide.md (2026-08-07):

# Wattplot v2 — Build Guide

> **STALE — written for the v2.4 / ESP32-WROOM-32 + BMI160 IMU +
> limit-switches architecture.** Pin numbers, sensor names, and
> entity IDs in this doc do not match `firmware/wattplot.yaml` v3.2.
> Use this as **design intent** (the build phases, sequence, and
> mechanical steps are still valid) and cross-check the electronics
> steps against:
>
> - Pin map: `docs/pinmap.html`
> - Schematic: `docs/schematic.html` (rev B, 2026-08-03)
> - Firmware config: `firmware/wattplot.yaml`
> - Firmware quick-start: `firmware/README.md`
>
> A future pass will regenerate this doc against the current YAML.
> Tracked in [ROADMAP.md](../ROADMAP.md).

Step-by-step assembly of the entire apparatus. Follow the order below.
Each step lists the **time**, **tools**, **parts**, and **verification**.

**Total build time:** ~10-15 hours over a weekend (with lumber pre-cut).

**Total cost:** ~$1,400 (per the BOM at `bom.md`).

---

## Phase 0: Pre-build (Day 0, ~1 hour)

### 0.1 Order lumber

From the BOM at `bom.md`:
- 12 × 1x6x8ft cedar (bed wall skin, 4 courses per wall)
- 4 × 2x4x8ft PT DF (wall cleats, 16 × 22" cuts)
- 2 × 2x6x8ft PT DF (wall caps, hinge + strut walls)
- 2 × 2x6x8ft PT DF (long rails)
- 2 × 2x6x8ft PT DF (cross rails)
- 1 × 2x4x10ft PT DF (diagonal brace)
- 1 × 2x4x8ft PT DF (fixed-tilt struts, Basic tier)
- 2 × 4x4x8ft PT DF (skids)

If your lumber yard offers FSC-certified DF, request it (small premium).
FSC chain-of-custody: ask for the certificate.

**Tip:** many yards will cut to length for free or a small fee. Have
them cut:
- 8 × 1x6 @ 96" (long wall skin, no cut needed from 8ft)
- 8 × 1x6 @ 43.1" (short wall skin, 2 per board from 8ft)
- 16 × 2x4 @ 22" (wall cleats, 4 per board)
- 2 × 2x6 @ 96" (wall caps, no cut)
- 2 × 2x6 @ 96" (long rails, no cut)
- 4 × 2x6 @ 42" (cross rails, 2 per board)
- 1 × 2x4 @ 102" (diagonal brace, cut from 10ft)
- 2 × 4x4 @ 96" (skids, no cut)

If they don't pre-cut, you'll need a circular saw or miter saw. None
of the cuts are mitered (90° only). A standard circular saw is enough.

### 0.2 Order hardware

- 4 × galvanized butt hinges 4"×4" leaf, ½" pin (Home Depot)
- 1 × ½" × 72" steel rod (Home Depot, in the steel rod section)
- 6 × aluminum mid-clamps 35mm channel (IronRidge / Unirac)
- 1 × ECO-WORTHY 12V 4" stroke 330 lbf linear actuator (Amazon)
- 1 × ½" × 3" clevis pin (McMaster)
- 8 × 3/8" × 4" carriage bolts HDG + washers + nuts (Home Depot)
- 8 × 5/16" × 3" lag bolts HDG (Home Depot)
- 24 × ¼" × 3" deck screws HDG Torx T-25 (Home Depot, 1 lb box)
- 1 lb box × 3" exterior deck screws (general)

### 0.3 Order the panel + electrical

- 1 × 620 W bifacial panel (LONGi Hi-MO X10 or similar)
- 1 × 12V 100Ah LiFePO4 battery (LiTime or similar)
- 1 × 30-40 A MPPT charge controller (Victron SmartSolar 100/30 ~$200,
  or EPEver Tracer 4210AN ~$140). See §7 below. The DPS5005 used in
  earlier revisions is retired — it was both a UART-controlled hack
  and undersized for the 620 W panel (5 A output, would have thrown
  away ~90% of the panel's potential).
- 1 × 12V LED grow light (20-30W, full spectrum)
- 1 × ESP32-WROOM-32E dev board (or use the PCB from `docs/pcb_design.md`)

### 0.4 Order the PCB (optional but recommended)

Send the design from `docs/pcb_design.md` to JLCPCB (5 pieces for $5+shipping).
While you wait (1-2 weeks), continue with the mechanical build.

---

## Phase 1: Bed (Day 1, ~3 hours)

### 1.1 Build the wall cleat frames

The walls are 1x6 cedar skin (¾", non-structural) screwed to vertical
2x4 cleats that carry the soil pressure. All square cuts, no notches.

**Tools:** circular saw, drill, impact driver, square

**Process:**
1. Cut 16 cleats: 2x4 @ 22" (4 per 8-ft board).
2. Long walls get 5 cleats each: one at each end, three between at
   ≤24" on center. Short walls get 3 each (ends + middle).
3. Stand a wall's cleats on a flat surface and screw the bottom skin
   course (1x6 @ 96" long walls / 43.1" short walls) across them with
   2 × #8 × 1¼" exterior screws per cleat. Square as you go.
4. Add the remaining 3 courses. Top of the 4th course = 22".

**Verification:** each wall panel is flat, square, and 22" tall with
cleats flush at top and bottom.

### 1.2 Assemble the bed box

**Tools:** drill, impact driver, square, level

**Process:**
1. Stand the 4 wall panels up. Short-wall skin ends butt into the
   long walls' end cleats — corners join cleat-to-cleat, not
   skin-to-skin.
2. Screw each corner: 4 × #10 × 3" exterior screws through the long
   wall's end cleat into the short wall's end cleat.
3. Lay the 2x6 caps flat on the south (hinge) and north (strut)
   walls, screwed down into every cleat top with #10 × 3" screws.
   The caps are what the hinges and strut shoes bite into.
4. Check the bed for square: measure diagonally both ways. Should be
   equal (~105" each).

**Verification:** bed box is 96" × 44.6" outside, walls plumb,
corners square, caps flush with the outer skin faces.

### 1.3 Attach the skids

**Tools:** drill, ¼" bit, impact driver, square

**Process:**
1. Flip the bed upside down.
2. Place two 4x4x8ft skids under the bed, aligned with the long
   walls. The skids extend 0" past the bed ends (flush).
3. Pre-drill 4 holes per skid (2 per end), ¼" pilot bit, through the
   skid and into the bed wall.
4. Drive ¼" × 3" deck screws through the skid into the wall.

**Verification:** skids are flush with the bed ends and square to the
bed. The bed sits flat on the skids.

### 1.4 Place the bed at the site

**Tools:** level, shovel (if site prep needed)

**Process:**
1. Move the bed to its final location. The bed is heavy (~150 lb empty,
   ~2000 lb with soil). Get help.
2. Level the bed in both directions (use shims under the skids if
   needed).
3. The bed should slope slightly toward the south (1-2% grade) for
   drainage. Adjust shims.

**Verification:** bed is level (or slightly tilted south), skids are
fully supported, no wobble.

---

## Phase 2: Frame (Day 1, ~2 hours)

### 2.1 Assemble the frame rectangle

**Tools:** drill, ¼" bit, impact driver, square, measuring tape

**Process:**
1. Lay the 4 frame rails (2 long + 2 cross) on a flat surface.
2. The cross rails fit between the long rails. Butt joints at the
   corners (no miter).
3. Pre-drill 2 holes per corner (through the cross rail into the long
   rail end), ¼" pilot bit.
4. Drive ¼" × 3" deck screws.
5. The frame interior should be 93" × 42" (PANEL_L - 2*RAIL_T) ×
   (CROSS_RAIL_L).
6. The frame exterior should be 96" × 45.6".

**Verification:** frame is square (measure diagonally), 96" × 45.6"
outside, 93" × 42" inside.

### 2.2 Add the diagonal brace

**Tools:** drill, ¼" bit, impact driver, measuring tape

**Process:**
1. The 2x4x102" diagonal brace runs corner to corner inside the frame.
2. Position the brace so its ends butt into the inside faces of the
   long rails.
3. The brace is at the height of the rails (sits on the bottom inside
   face of the long rails, or just above).
4. Pre-drill 2 holes per end (through the brace into the long rail
   inside face), ¼" pilot bit.
5. Drive ¼" × 3" deck screws.

**Verification:** brace is at the correct diagonal angle (~24°), both
ends are screwed to the long rails. Frame is now rigid (no racking).

### 2.3 Install hinges on the bed's south wall

**Tools:** drill, 5/16" bit, impact driver with socket, measuring tape

**Process:**
1. Lay the frame on top of the bed, with the frame's south rail
   resting on the bed's south wall.
2. Position the 4 hinges evenly along the south rail: spacing 22",
   centered, 4" margin on each end of the 96" wall.
3. Mark the hinge positions on both the frame's south rail and the
   bed's south wall.
4. Pre-drill 4 holes per hinge (2 per leaf), 5/16" bit for the lag
   bolts.
5. Attach the wall leaf of each hinge to the bed's south wall with
   5/16" × 3" lag bolts.
6. Attach the frame leaf of each hinge to the frame's south rail
   with 5/16" × 3" lag bolts.
7. The frame should now hinge freely on the south wall.

**Verification:** frame hinges smoothly between 0° and 90° tilt. No
binding. The ½" hinge pin holes in all 4 hinges are aligned (the
continuous pin will pass through all 4).

### 2.4 Insert the continuous hinge pin

**Tools:** mallet (rubber), ½" drill bit (if pin is too tight)

**Process:**
1. Thread the ½" × 72" steel rod through all 4 hinges, starting from
   one end.
2. Tap gently with a rubber mallet to seat the pin fully.
3. The pin should extend ~1" past the last hinge on each end.

**Verification:** pin is fully seated. The frame hinges smoothly with
the pin in place.

---

## Phase 3: Panel (Day 2, ~1 hour)

### 3.1 Lift the panel onto the frame

**Tools:** helper(s), ladder if needed

**Process:**
1. The 620 W bifacial panel weighs ~65 lb. Get help.
2. With the frame flat (0°), place the panel inside the frame, centered.
3. The panel frame (aluminum) should sit on top of the wood frame.

**Verification:** panel is centered, frame interior clearances are
even on all sides.

### 3.2 Clamp the panel to the frame

**Tools:** drill, 5/16" hex driver, M8 wrench, ladder if needed

**Process:**
1. Place 2 mid-clamps per long rail (4 total), at positions ±24" from
   the panel center (4 evenly spaced clamps along the 96" rail).
2. Place 1 mid-clamp per cross rail (2 total), at the panel center
   (each side of the panel, where the cross rail meets the panel).
3. Tighten the M8 bolts to clamp the panel frame to the wood rails.
4. Torque to ~10 Nm (snug, not crushing).

**Verification:** panel is firmly attached. Try to wiggle it — should
not move.

### 3.3 Install the actuator

**Tools:** drill, ½" bit, 9/16" wrench, 2× helpers

**Process:**
1. The actuator is between the bed's north wall and the frame's north
   rail.
2. Mount the wall-side clevis block (2x6 PT, 6" long) on top of the
   bed's north wall, near the bed's center.
3. Mount the frame-side clevis block on the inside face of the frame's
   north rail, near the bed's center.
4. The actuator's body is on the frame-side, the rod extends toward
   the wall.
5. Pin the actuator to the wall block with the ½" × 3" clevis pin.
6. Pin the actuator's rod end to the frame block with another clevis
   pin (or use the same pin if the actuator has both ends pinned).

**Verification:** actuator is mounted, rod can extend and retract. Frame
can be tilted by hand from 0° to 90°.

---

## Phase 4: Sensors and Wiring (Day 2, ~3 hours)

### 4.1 Install the IMU on the frame

Follow `docs/sensor_placement.md` § 1.

**Tools:** drill, #4 wood screws, small Phillips, foam adhesive pad

**Process:**
1. Mount the BMI160 breakout board on the **underside** of the frame's
   north rail, centered.
2. Use 2× #4 wood screws through the breakout's mounting holes.
3. Add a small foam adhesive pad between the breakout and the wood to
   dampen vibration.
4. Run the 4-wire I2C cable along the north rail to the cable carrier.

### 4.2 Install the limit switches

Follow `docs/sensor_placement.md` § 6.

**Tools:** drill, small wood screws

**Process:**
1. Mount the **0° switch** on a small wood block on the bed's south
   wall, just below the hinge axis. The roller faces the frame's
   south rail.
2. Mount the **90° switch** on a small wood block on the bed's north
   wall, near the actuator mount. The roller faces the frame's north
   rail.
3. Test by tilting the frame by hand:
   - At 0° (flat), the 0° switch should be pressed.
   - At 90° (vertical), the 90° switch should be pressed.
4. Run the 3-wire cable (signal, signal, GND) from the switches to the
   PCB.

### 4.3 Install the soil sensors

Follow `docs/sensor_placement.md` § 3-4.

**Tools:** shovel, drill (for grommet holes), screwdriver

**Process:**
1. Drill a ½" hole in the bed's south wall, 12" from the east end
   (for the soil cables).
2. Insert a rubber grommet in the hole.
3. Push the DS18B20 probe into the soil to 6" depth, 12" from the
   south wall, 24" from the east end.
4. Push the soil moisture sensor into the soil to 4" depth, 18" from
   the south wall, 24" from the east end.
5. Run the cables through the grommet, up the south wall, into the
   cable carrier, to the PCB.

### 4.4 Mount the PCB enclosure

**Tools:** drill, #10 wood screws, level

**Process:**
1. Mount the PCB enclosure on the bed's east short wall, at table
   height (~30" above ground).
2. The enclosure should be accessible for service (not buried in
   foliage).
3. Use 4× #10 wood screws through the enclosure's mounting feet into
   the bed wall.
4. Verify the enclosure is level (for any internal status displays).

### 4.5 Wire the PCB to all components

Follow `docs/wiring.md`.

**Tools:** wire stripper, JST-XH crimper, screwdriver, multimeter

**Process:** connect each cable as described in the wiring table.
**Do not install the battery fuse yet.**

### 4.6 Continuity check

**Tools:** multimeter

Before applying power, verify:
- [ ] No shorts between 12V and GND (multimeter continuity)
- [ ] No shorts between 3V3 and GND
- [ ] No shorts between 5V and GND
- [ ] Each limit switch closes when pressed (0 Ω when activated)
- [ ] All JST-XH connectors are fully seated
- [ ] No bare wire exposed at any connector

---

## Phase 5: Battery and First Power-On (Day 2, ~1 hour)

### 5.1 Connect the battery

**Tools:** multimeter, 5A fuse

**Process:**
1. Place the 12V LiFePO4 battery on the ground next to the bed (or
   in a small battery box).
2. Connect the battery negative to the PCB enclosure's ground bus.
3. Connect the battery positive through a 5A in-line fuse, then to
   the PCB's J1+ terminal.
4. **Do not install the fuse yet.** Leave the fuse holder empty.

### 5.2 Install the fuse and power on

**Tools:** USB cable, laptop

**Process:**
1. With the laptop connected via USB-C to the PCB's J3, install the
   fuse.
2. The ESP32 should boot. The status LED should light up (any color
   means power is on).
3. Open the Arduino IDE or ESPHome flasher. Verify the ESP32 is
   detected.
4. Flash the firmware: `esphome run firmware/wattplot.yaml`.

### 5.3 Verify boot

**Tools:** serial monitor

**Process:**
1. Open the serial monitor (115200 baud).
2. Look for ESPHome boot messages. Should see:
   - "Wattplot Controller" branding
   - "BMI160" detected
   - "INA219" detected
   - "DS18B20" detected
   - State: FOLDING (safe default)

> The full-size v2 build re-instantiates the MPPT UART/RS-485 link
> that was removed from the mini firmware (see `firmware/README.md`).
> The PCB's J4 footprint is now populated, GPIO 26/27 are now bound
> to the new MPPT's comms port, and the firmware's MPPT loop and
> charge-controller readback return. The mini build (v2.4) does not
> have any of this — the Sunapex is standalone.

### 5.4 Test each sensor

**Tools:** serial monitor, web browser (Home Assistant)

For each sensor, verify it's reading sensible values:
- [ ] IMU: tilt = ~0° when frame is flat, ~35° when tilted
- [ ] INA219: current = ~0 A when actuator is stationary
- [ ] DS18B20: temp = ~70-80°F in Phoenix afternoon
- [ ] Soil moisture: ~30-60% depending on soil wetness
- [ ] Battery voltage: ~12.0-13.5 V (LiFePO4 range)
- [ ] Limit switches: HIGH when open, LOW when pressed
- [ ] MPPT: responds to UART/RS-485 commands (Victron VE.Direct or EPEver Modbus)

---

## Phase 6: Soil and Planting (Day 2-3, ~1 hour)

### 6.1 Fill the bed with soil

**Tools:** wheelbarrow, shovel, rake

**Process:**
1. Fill the bed with 11.25" of soil (1 cubic yard = 27 cu ft, bed
   interior is 93" × 41.6" × 11.25" = 30.1 cu ft = 1.1 cu yd).
2. Use a 50/50 mix of native soil and compost. Or just compost.
3. Wet the soil to settle it.

### 6.2 Plant tomatoes

**Tools:** trowel, tomato seedlings, fertilizer

**Process:**
1. Plant 4 tomato seedlings, one in each quadrant of the bed
   (16" from each wall, evenly spaced).
2. Use a 6-24-24 starter fertilizer at planting.
3. Install drip irrigation (optional but recommended for consistent
   watering).

### 6.3 Install the grow light (if used)

**Tools:** drill, screws, 12V LED fixture

**Process:**
1. Bolt the grow light fixture to the top of the frame's east and
   west cross rails.
2. Run the 12V switched wire from PCB J5 to the light, through the
   cable carrier.
3. Test by toggling the grow light from Home Assistant.

---

## Phase 7: Final Wiring and Validation (Day 3, ~1 hour)

### 7.1 Connect the solar panel

**Tools:** MC4 crimper, wire stripper

**Process:**
1. Mount the 620W bifacial panel on the frame (already done in
   Phase 3).
2. Run the MC4 cables from the panel's junction box down through the
   cable carrier to the PCB enclosure.
3. Splice the panel leads: one leg to the microinverter (240 VAC), one
   leg to the **30-40 A MPPT** (Victron SmartSolar 100/30 or EPEver
   Tracer 4210AN) input for MPPT battery charging. The MPPT's
   VE.Direct / RS-485 port connects to the PCB's J4 (GPIO 26/27) for
   telemetry.
4. The microinverter is its own certified box — install per its
   instructions.

### 7.2 Validate the state machine

**Tools:** serial monitor, web UI

**Process:**
1. With everything connected, the firmware should be in FOLDING state
   (safe default).
2. Verify the state transitions:
   - Send a command to go to NORMAL → frame tilts to 35° via the
     actuator, IMU reads 35°, INA219 reads 0 A.
   - Send a command to go to BEDSUN → frame tilts to 90° (vertical).
   - Send a command to go back to FOLDING → frame tilts to 0° (flat).
3. Check the decision stack:
   - Disconnect WiFi → state should still update (offline mode).
   - Mock a high-wind NWS forecast → state should go to FOLDING.
   - Disconnect the IMU → watchdog should trigger, state should go to
     FOLDING.

### 7.3 Test the MPPT

**Tools:** multimeter

**Process:**
1. With the panel exposed to sun, the MPPT should be outputting
   ~14.4 V to the battery (bulk charge for LiFePO4).
2. The battery voltage should rise slowly during the day.
3. Verify the ESP32 can read MPPT telemetry (panel V, panel I, charge
   state, battery V) over VE.Direct / RS-485 — the new `mppt_step`
   loop and `sensor.mppt_*` entities should populate. Use the
   ESPHome web UI to verify values.

### 7.4 Test the DLI grow light

**Tools:** serial monitor, web UI

**Process:**
1. With the panel in NORMAL state, check the DLI reading (mol/m²/day).
2. If DLI is below target, the grow light should come on.
3. Verify the light turns on (visually) and the timer limits to 16
   hours on / 8 hours off.

---

## Phase 8: Documentation (Day 3, ~30 min)

### 8.1 Take build photos

Follow the **photo template** in the README (Build section).

### 8.2 Log the build

In `docs/build_log.md` (create it), write:
- Date and time of each phase
- Any deviations from this guide
- Any issues encountered
- Photos (with captions)

### 8.3 Update the README

In the main README, add the build photos to the "Build photos" section.

---

## Build checklist (final, before considering the build "done")

- [ ] Bed is level, square, and full of soil
- [ ] Frame hinges smoothly from 0° to 90°
- [ ] Hinge pin is fully seated
- [ ] Panel is firmly clamped to the frame
- [ ] Actuator is mounted and pinned
- [ ] IMU is reading tilt correctly
- [ ] Limit switches trigger at 0° and 90°
- [ ] Soil sensors are reading
- [ ] Battery is connected and charging
- [ ] Solar panel is producing power (MPPT output is 14.4V)
- [ ] Microinverter is grid-tied (240 VAC out)
- [ ] ESP32 is online in Home Assistant
- [ ] State machine transitions are working
- [ ] DLI grow light is operating correctly
- [ ] All grommets are sealed
- [ ] Conformal coating is applied to the PCB (optional but recommended)

**Build complete.** Enjoy the tomatoes and the kWh.

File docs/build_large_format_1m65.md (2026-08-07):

# Wattplot Build Guide: large_format_1m65

> **STALE — auto-generated from the same template as `build_guide.md`
> (which is itself stale).** The panel-preset-specific geometry (Phase 0
> lumber cut list, Phase 1 bed dimensions) is correct for the large-format
> 1.65 m² preset; the **electronics phases** (Phase 7 onward) reference
> the v2.4 architecture that no longer exists. See `firmware/README.md`
> and `docs/pinmap.html` for the current truth. Tracked in
> [ROADMAP.md](../ROADMAP.md).

Step-by-step assembly of the entire apparatus. Follow the order below. Each step lists the **time**, **tools**, **parts**, and **verification**.

**Total build time:** ~7.9 hr over a weekend (with lumber pre-cut).

**Specifications for this build:**
- Panel: 65.0" × 41.0" × 1.4" (5.42 × 3.42 ft), 41.0 lb
- Wattage: 392 W (nameplate 400 W, derated after 4 yr, bifacial)
- Bed: 65.0" × 41.0" (5.42 × 3.42 ft), 12" deep walls, bottomless

## Phase 0: Pre-build (Day 0, ~1.0 hr)

### 0.1 Lumber (from the cut list)

| Nominal | Qty | Length | Use |
|---|---|---|---|
| 1x6 | 10 | 65.0" (5.42 ft) | long wall skin (N/S), 4 courses |
| 1x6 | 10 | 39.5" (3.29 ft) | short wall skin (W/E), 4 courses |
| 2x4 | 16 | 27.5" (2.29 ft) | wall cleat (vertical, <=24" o.c.) |
| 2x6 | 2 | 65.0" (5.42 ft) | wall cap, hinge + strut walls |
| 2x6 | 2 | 65.0" (5.42 ft) | long frame rail |
| 2x6 | 2 | 38.0" (3.17 ft) | cross frame rail |
| 2x4 | 1 | 76.9" (6.40 ft) | diagonal brace |
| 4x4 | 2 | 65.0" (5.42 ft) | long skid |

**Source from 8-ft stock:** 15× 1x6, 7× 2x4, 5× 2x6, 2× 4x4

**Tip:** many yards will cut to length for free or a small fee. Have them cut each piece on the list above. None of the cuts are mitered (90° square cut only).

### 0.2 Hardware

- 2 × galvanized butt hinge, 4.0"×4.0" leaf, 0.5" pin, HDG
- 1 × ½" × 67.0" steel rod (continuous, through all hinges)
- 6 × aluminum mid-clamps, 35mm channel, M8 SS bolt + EPDM washer
- 8 × 3/8" × 4" carriage bolt HDG + washer + hex nut (bed corner joints)
- 8 × 5/16" × 3" lag bolt HDG (hinge leaf to bed wall)
- 18 × ¼" × 3" deck screw HDG Torx T-25
- 1 × 12V linear actuator, 4.0" stroke, IP65

### 0.3 Panel + electrical

- 1 × **400 W nameplate (392 W after derate) salvage panel** (you provide)
  - Verify under full sun: Voc within 5% of nameplate (multimeter)
  - Glass intact, no cracks or delamination
  - Aluminum frame straight, junction box sealed
- 1 × MPPT charge controller (sized to your panel, see `bring_your_own_panel.py`)
- 1 × 12V 100Ah LiFePO4 battery (LiTime or similar)
- 1 × Microinverter (Enphase IQ7+ or APsystems DS3)
- 1 × ESP32-WROOM-32E dev board (or use the PCB from `docs/pcb_design.md`)

## Phase 1: Bed (Day 1, ~1.9 hr)

### 1.1 Cut the wall half-lap notches

Each bed wall has a 3" wide × 0.75" deep notch at each end.

**Tools:** circular saw, chisel, mallet, square

**Process:**
1. Mark the notch location on each wall (3" from each end, 0.75" deep).
2. Make multiple passes with the circular saw at the notch depth.
3. Clean out the waste with a chisel.
4. Test-fit two walls at a corner.

**Verification:** the two walls meet at a 90° corner with no daylight.

### 1.2 Assemble the bed box

**Tools:** drill, ⅛" pilot bit, #6 × 1.5" wood screws, square

**Process:**
1. Lay out the 4 walls on a flat surface. Long walls are 65.0" (5.42 ft). Short walls are 38.0" (3.17 ft).
2. Bring the corners together. The half-lap notches interlock.
3. Pre-drill 2 holes per corner (one near the top, one near the bottom).
4. Drive #6 × 1.5" wood screws through the corners.

**Verification:** bed box is 65.0" × 41.0" outside, square (measure diagonally, both should be the same).

### 1.3 Attach the skids

**Tools:** drill, ⅛" pilot bit, #6 × 1.5" screws

**Process:**
1. Flip the bed upside down.
2. Place two 4x4×65.0" skids under the bed, aligned with the long walls.
3. Pre-drill and screw through the skids into the bed walls.
4. Use 2-3 screws per skid.

**Verification:** skids are flush with the bed ends, square, and the whole bed sits level on the ground.

## Phase 2: Frame (Day 1, ~1.2 hr)

### 2.1 Assemble the frame rectangle

**Tools:** drill, ⅛" pilot bit, #6 × 1.5" wood screws, square

**Process:**
1. Lay the 4 frame rails on a flat surface. Long rails are 65.0" (5.42 ft). Cross rails are 38.0" (3.17 ft).
2. The cross rails fit between the long rails. Butt joints (no miter).
3. Pre-drill 2 holes per corner. Drive #6 × 1.5" wood screws.

**Verification:** frame is 65.0" × 41.0" outside, square.

### 2.2 Add the diagonal brace

**Tools:** drill, ⅛" pilot bit, #6 × 1" screws, measuring tape

**Process:**
1. The 2x4×76.9" diagonal brace runs corner to corner inside the frame.
2. Position the brace so its ends butt into the inside faces of the long rails.
3. Pre-drill 2 holes per end. Drive #6 × 1" screws (4 total).

**Verification:** brace is at the diagonal angle, both ends screwed.

## Phase 3: Hinges (Day 1, ~20 min)

### 3.1 Install hinges on the bed's south wall

**Tools:** drill, 5/64" bit, hinge screws (included with hinges), tape measure

**Process:**
1. Lay the frame on top of the bed, with the frame's south rail resting on the bed's south wall.
2. Position the 2 hinges evenly along the south rail. Spacing: 57.0" center-to-center, with 4" margin on each end.
3. Mark the hinge positions on both the frame's south rail and the bed's south wall.
4. Pre-drill 4 holes per hinge (2 per leaf), 5/64" bit.
5. Attach the wall leaf to the bed's south wall.
6. Attach the frame leaf to the frame's south rail.

**Verification:** frame hinges freely between 0° and ~90° tilt.

### 3.2 Insert the continuous hinge pin

**Tools:** mallet (rubber)

**Process:**
1. Thread the ½" × 67.0" steel rod through all hinges, starting from one end.
2. Tap gently with a rubber mallet to seat the pin fully.
3. The pin should extend ~1" past the last hinge on each end.

**Verification:** pin is fully seated. Frame hinges smoothly with the pin in place.

## Phase 4: Panel (Day 1, ~11 min)

### 4.1 Place the panel on the frame

**Tools:** hands (the panel weighs 41.0 lb).

**Process:**
1. With the frame flat on the bed, place the panel on top of the frame, centered.
2. The panel should rest on the wood rails with even margin on all four sides.

**Verification:** panel is centered, no overhang on the long rails.

### 4.2 Clamp the panel to the frame

**Tools:** drill, M8 hex driver, mid-clamps

**Process:**
1. Place 4 mid-clamps on each long rail (8 total, evenly spaced along the panel frame).
2. Place 2 mid-clamps on each cross rail.
3. Tighten the M8 bolts to clamp the panel frame to the wood rails.
4. Torque to ~3 Nm (snug, not crushing).

**Verification:** panel is firmly attached. Try to wiggle it: should not move.

## Phase 5: Actuator Mount (Day 1, ~20 min)

### 5.1 Mount the bottom block on the bed's north wall

**Tools:** drill, ⅛" pilot bit, #6 × 1.5" wood screws

**Process:**
1. Cut a 3" length of 2x6 (offcut from any 2x6 scrap).
2. Mount the block on the outer face of the bed's north wall, at the bottom.
3. Centered along the bed length.
4. Pre-drill 2 holes and drive #6 × 1.5" screws.

### 5.2 Mount the top bracket on the panel's underside

1. Cut a 3" length of 2x6 (offcut).
2. Mount on the **underside** of the panel, 2" north of the panel's south edge.
3. The bracket should sit just below the panel's underside, flush with the panel's south frame edge.
4. Pre-drill and drive #6 × 1.5" wood screws through the bracket into the panel frame.

### 5.3 Connect the actuator

1. Use ⅜" clevis pins to attach the actuator to both mount blocks.
2. Test manually: the panel should now move from 0° to ~90° (or your actuator's stroke limit).

## Phase 6: Wire the panel to MPPT (Day 2, ~30 min)

### 6.1 MC4 connectors

**Tools:** MC4 crimper, wire stripper, multimeter

**Process:**
1. Crimp MC4 connectors on the panel's PV+ and PV- leads.
2. Plug into the MPPT's PV input (MC4 or SAE adapter, depending on the MPPT).
3. **Verify polarity**: red → +PV, black → -PV. Reverse polarity kills MPPT.

### 6.2 MPPT to battery

1. Connect MPPT battery output to the 12V LiFePO4 battery (via ring terminals or Anderson).
2. Set the MPPT's battery chemistry to LiFePO4 (MODE button on Sunapex).
3. The MPPT status LED should turn on (green = charging or float).

**Verification:** under sun, panel Voc on multimeter matches nameplate ±5%. Battery voltage rises over the next hour.

## Phase 7: Wire the controller (Day 2, ~1.0 hr)

### 7.1 ESP32 + sensors

**Tools:** soldering iron (or perfboard), wire stripper, multimeter

**Pins (from `firmware/wattplot.yaml`):**

| GPIO | Function |
|---|---|
| 4 | DS18B20 1-Wire data |
| 5 | Watering solenoid |
| 16, 17, 18 | H-bridge IN1, IN2, EN |
| 19 | Grow light relay |
| 21, 22 | I2C SDA, SCL |
| 25 | WS2812B status LED |
| 32 | Soil moisture ADC |
| 33 | Battery voltage ADC |
| 34, 35 | Limit switches (0° and 90°) |

### 7.2 Power

1. Connect the DRV8871 H-bridge to the 12V battery (via a 5A fuse).
2. Connect the ESP32's VIN to a 5V buck converter on the 12V rail.
3. Verify all grounds are common.

### 7.3 IMU + INA219 + DS18B20

1. Mount the BMI160 on the panel (under the north rail). I2C address 0x68.
2. Mount the INA219 in series with the actuator (high side). I2C address 0x40.
3. Mount the DS18B20 in the bed soil.
4. All sensors share the I2C bus: SDA (GPIO 21), SCL (GPIO 22), 3.3V, GND.

**Verification:** ESPHome logs show all sensors reporting values.

## Phase 8: Flash ESPHome (Day 2, ~30 min)

### 8.1 First flash over USB

```bash
# Install ESPHome (if not already)
pip install esphome

# Flash the firmware
esphome run firmware/wattplot.yaml
```

### 8.2 WiFi + Home Assistant (optional)

1. Set WiFi credentials in `firmware/secrets.yaml`.
2. Re-flash. ESP32 connects to WiFi and exposes all entities to Home Assistant.
3. Add the ESPHome integration in HA. Entities appear automatically.

## Phase 9: Calibrate + test (Day 2, ~1.0 hr)

### 9.1 IMU zero-tilt offset

1. With the panel flat (0°), read the BMI160's pitch value via ESPHome log.
2. That reading is your zero-tilt offset. Subtract it in the firmware.
3. Re-flash.

### 9.2 Motor current calibration

1. Manually drive the panel to 35°. Read the INA219 current (idle, no wind).
2. Set that as the `target_current_A` in `firmware/wattplot.yaml`.
3. Set `I_safe_A` just above the stall current (typically 2.5A for DRV8871).

### 9.3 Limit switches

1. Drive the panel to 0° (limit switch 0). Adjust switch position so it trips cleanly.
2. Drive to 90° (limit switch 1). Same.
3. Verify the firmware auto-stops at both limits.

### 9.4 End-to-end test

1. Open Home Assistant. Verify all sensors reporting.
2. Trigger a manual tilt from HA. Verify panel moves.
3. Press the user-override button. Verify it overrides the decision stack.
4. Leave it running for 24 hours. Check logs for any errors.

---

**Total time:** ~7.9 hr (with pre-cut lumber and a clean workspace).

**Total cost:** see `python bring_your_own_panel.py` for an itemized estimate.

**Next:** see `docs/test_checklist.md` for per-component and per-system tests.

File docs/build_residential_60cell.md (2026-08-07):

# Wattplot Build Guide: residential_60cell

> **STALE — auto-generated from the same template as `build_guide.md`
> (which is itself stale).** The panel-preset-specific geometry (Phase 0
> lumber cut list, Phase 1 bed dimensions) is correct for the 60-cell
> residential preset; the **electronics phases** (Phase 7 onward) reference
> the v2.4 architecture that no longer exists. See `firmware/README.md`
> and `docs/pinmap.html` for the current truth. Tracked in
> [ROADMAP.md](../ROADMAP.md).

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

**Total build time:** ~7.9 hr over a weekend (with lumber pre-cut).

**Specifications for this build:**
- Panel: 65.0" × 39.0" × 1.6" (5.42 × 3.25 ft), 38.0 lb
- Wattage: 235 W (nameplate 250 W, derated after 12 yr, monofacial)
- Bed: 65.0" × 39.0" (5.42 × 3.25 ft), 12" deep walls, bottomless

## Phase 0: Pre-build (Day 0, ~1.0 hr)

### 0.1 Lumber (from the cut list)

| Nominal | Qty | Length | Use |
|---|---|---|---|
| 2x12 | 2 | 65.0" (5.42 ft) | long bed wall (north/south) |
| 2x12 | 2 | 36.0" (3.00 ft) | short bed wall (west/east) |
| 2x6 | 2 | 65.0" (5.42 ft) | long frame rail |
| 2x6 | 2 | 36.0" (3.00 ft) | cross frame rail |
| 2x4 | 1 | 75.8" (6.32 ft) | diagonal brace |
| 4x4 | 2 | 65.0" (5.42 ft) | long skid |

**Source from 8-ft stock:** 4× 2x12, 2× 2x6, 1× 2x4, 2× 4x4

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

### 0.2 Hardware

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

### 0.3 Panel + electrical

- 1 × **250 W nameplate (235 W after derate) salvage panel** (you provide)
  - Verify under full sun: Voc within 5% of nameplate (multimeter)
  - Glass intact, no cracks or delamination
  - Aluminum frame straight, junction box sealed
- 1 × MPPT charge controller (sized to your panel, see `bring_your_own_panel.py`)
- 1 × 12V 100Ah LiFePO4 battery (LiTime or similar)
- 1 × Microinverter (Enphase IQ7+ or APsystems DS3)
- 1 × ESP32-WROOM-32E dev board (or use the PCB from `docs/pcb_design.md`)

## Phase 1: Bed (Day 1, ~1.9 hr)

### 1.1 Cut the wall half-lap notches

Each bed wall has a 3" wide × 0.75" deep notch at each end.

**Tools:** circular saw, chisel, mallet, square

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

**Verification:** the two walls meet at a 90° corner with no daylight.

### 1.2 Assemble the bed box

**Tools:** drill, ⅛" pilot bit, #6 × 1.5" wood screws, square

**Process:**
1. Lay out the 4 walls on a flat surface. Long walls are 65.0" (5.42 ft). Short walls are 36.0" (3.00 ft).
2. Bring the corners together. The half-lap notches interlock.
3. Pre-drill 2 holes per corner (one near the top, one near the bottom).
4. Drive #6 × 1.5" wood screws through the corners.

**Verification:** bed box is 65.0" × 39.0" outside, square (measure diagonally, both should be the same).

### 1.3 Attach the skids

**Tools:** drill, ⅛" pilot bit, #6 × 1.5" screws

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

## Phase 2: Frame (Day 1, ~1.2 hr)

### 2.1 Assemble the frame rectangle

**Tools:** drill, ⅛" pilot bit, #6 × 1.5" wood screws, square

**Process:**
1. Lay the 4 frame rails on a flat surface. Long rails are 65.0" (5.42 ft). Cross rails are 36.0" (3.00 ft).
2. The cross rails fit between the long rails. Butt joints (no miter).
3. Pre-drill 2 holes per corner. Drive #6 × 1.5" wood screws.

**Verification:** frame is 65.0" × 39.0" outside, square.

### 2.2 Add the diagonal brace

**Tools:** drill, ⅛" pilot bit, #6 × 1" screws, measuring tape

**Process:**
1. The 2x4×75.8" diagonal brace runs corner to corner inside the frame.
2. Position the brace so its ends butt into the inside faces of the long rails.
3. Pre-drill 2 holes per end. Drive #6 × 1" screws (4 total).

**Verification:** brace is at the diagonal angle, both ends screwed.

## Phase 3: Hinges (Day 1, ~20 min)

### 3.1 Install hinges on the bed's south wall

**Tools:** drill, 5/64" bit, hinge screws (included with hinges), tape measure

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

**Verification:** frame hinges freely between 0° and ~90° tilt.

### 3.2 Insert the continuous hinge pin

**Tools:** mallet (rubber)

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

**Verification:** pin is fully seated. Frame hinges smoothly with the pin in place.

## Phase 4: Panel (Day 1, ~11 min)

### 4.1 Place the panel on the frame

**Tools:** hands (the panel weighs 38.0 lb).

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

**Verification:** panel is centered, no overhang on the long rails.

### 4.2 Clamp the panel to the frame

**Tools:** drill, M8 hex driver, mid-clamps

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

**Verification:** panel is firmly attached. Try to wiggle it: should not move.

## Phase 5: Actuator Mount (Day 1, ~20 min)

### 5.1 Mount the bottom block on the bed's north wall

**Tools:** drill, ⅛" pilot bit, #6 × 1.5" wood screws

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

### 5.2 Mount the top bracket on the panel's underside

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

### 5.3 Connect the actuator

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

## Phase 6: Wire the panel to MPPT (Day 2, ~30 min)

### 6.1 MC4 connectors

**Tools:** MC4 crimper, wire stripper, multimeter

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

### 6.2 MPPT to battery

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

## Phase 7: Wire the controller (Day 2, ~1.0 hr)

### 7.1 ESP32 + sensors

**Tools:** soldering iron (or perfboard), wire stripper, multimeter

**Pins (from `firmware/wattplot.yaml`):**

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

### 7.2 Power

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

### 7.3 IMU + INA219 + DS18B20

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

**Verification:** ESPHome logs show all sensors reporting values.

## Phase 8: Flash ESPHome (Day 2, ~30 min)

### 8.1 First flash over USB

```bash
# Install ESPHome (if not already)
pip install esphome

# Flash the firmware
esphome run firmware/wattplot.yaml
```

### 8.2 WiFi + Home Assistant (optional)

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

## Phase 9: Calibrate + test (Day 2, ~1.0 hr)

### 9.1 IMU zero-tilt offset

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

### 9.2 Motor current calibration

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

### 9.3 Limit switches

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

### 9.4 End-to-end test

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

---

**Total time:** ~7.9 hr (with pre-cut lumber and a clean workspace).

**Total cost:** see `python bring_your_own_panel.py` for an itemized estimate.

**Next:** see `docs/test_checklist.md` for per-component and per-system tests.

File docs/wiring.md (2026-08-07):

# Wattplot v2 — Wiring Diagram

> **STALE — written for the v1 PCB (ESP32-WROOM-32E, BMI160, limit
> switches, GPIO4 DS18B20, GPIO16/17/18 DRV8871, GPIO19 grow-light
> relay, GPIO32 soil, GPIO33 battery, GPIO34/35 limits).** The current
> hardware is **ESP32-S3, schematic rev B (2026-08-03)**, with the
> pin map and BOM significantly changed. Use this as design intent
> (the harness topology, fusing, and outdoor-wiring practices are
> still valid) and cross-check every pin against:
>
> - Pin map: `docs/pinmap.html`
> - Schematic: `docs/schematic.html` (rev B, 2026-08-03)
> - Firmware config: `firmware/wattplot.yaml`
> - Firmware quick-start: `firmware/README.md`
>
> A future pass will regenerate this doc against the current schematic.
> Tracked in [ROADMAP.md](../ROADMAP.md).

Pin-by-pin wiring from the **Wattplot Controller v1 PCB** (in its
waterproof enclosure, mounted on the bed's east short wall) to every
component on the apparatus. The PCB pin map is in `docs/pcb_design.md`.

**Wire types:** All low-voltage signal wires are 22-26 AWG stranded
(silicone-jacketed for outdoor use, e.g., EcoWire). The 12 V battery
and grow light cables are 16-14 AWG (use silicone wire for flexibility,
e.g., 14 AWG silicone from a hoverboard battery supply). Solar panel
leads are MC4 (the panel ships with them); the Sunapex ships with
**SAE connectors** on both sides plus a polarity reversal adapter, so
the panel MC4 connects directly to the Sunapex's SAE adapter on the
PV input. No MC4-to-bare-wire pigtail needed.

**Cable lengths** are the runs from PCB to component, with ~6" of slack
at each end for service. JST-XH connectors at the PCB side; bare wire or
ring terminals at the component side.

**Charge controller:** the **Sunapex 10A MPPT** (mini build) is a
standalone waterproof charge controller — it has no host connection, runs
its own MPPT, and handles bulk/absorption/float for LiFePO4. The ESP32
only *reads* battery voltage via the on-PCB 10 kΩ / 10 kΩ divider on
GPIO 33; the controller's own battery sense is what actually gates
charging. The full-size v2 build (620 W panel) needs a larger MPPT
sized to that panel — see `docs/build_guide.md` §7.

---

## 1. PCB header → component map

### Power (12 V battery)

| PCB header | Wire | Goes to | Notes |
|---|---|---|---|
| J1 pin 1 (+) | 12 AWG red, ~24" | Battery (+) terminal | Through 5A in-line fuse within 6" of battery |
| J1 pin 2 (−) | 12 AWG black, ~24" | Battery (−) terminal | Common ground |

### USB-C programming

| PCB header | Wire | Goes to | Notes |
|---|---|---|---|
| J3 | USB-C cable | External laptop (only for first flash) | After that, OTA updates via WiFi |

### I2C bus (BMI160 IMU, INA219, expansion)

| PCB header | Wire | Goes to | Notes |
|---|---|---|---|
| J2 pin 1 | 26 AWG red, ~36" | 3V3 rail (powers IMU + INA219) | Twisted with SDA/SCL |
| J2 pin 2 | 26 AWG black, ~36" | Common GND | |
| J2 pin 3 | 26 AWG white, ~36" | SDA — daisy-chain IMU → INA219 | I2C SDA |
| J2 pin 4 | 26 AWG green, ~36" | SCL — daisy-chain IMU → INA219 | I2C SCL |

The IMU is mounted on the panel frame (to measure actual tilt). The
INA219 is on the motor lead (to measure actuator current). Both sit on
the same I2C bus; daisy-chain with 4-wire cable.

### UART (DPS5005 MPPT controller)

> **Removed in v2.4** — replaced by the **Sunapex 10A MPPT** standalone
> MPPT (see "Solar charge controller" below). The Sunapex has no host
> connection; ESP32 only reads battery voltage through the divider.
> The PCB's J4 footprint and GPIO 26 / 27 pads remain on the board but
> are unpopulated (DNP) on the mini build — they are reserved for the
> full-size v2's larger MPPT (RS-485 or VE.Direct).
>
> On the full-size v2 build, this section returns with whatever UART/
> RS-485 the chosen MPPT uses (e.g., Victron VE.Direct on UART2 for
> telemetry, or EPEver RS-485 Modbus). The pin map stays the same
> (GPIO 26/27, J4 footprint).

### Solar charge controller (Sunapex 10A MPPT, mini only)

The Sunapex has **no host connection**. It sits on the bed wall, has
its own internal MPPT, bulk/absorption/float for LiFePO4, and all
charging protections. The PCB does not talk to it.

| Wire | Goes to | Notes |
|---|---|---|
| Panel MC4 + (red) | Sunapex **PV+** (via included SAE adapter) | Polarity reversal adapter included with Sunapex |
| Panel MC4 − (black) | Sunapex **PV−** (via included SAE adapter) | |
| Sunapex **BAT+** (SAE) | 12 V battery + (through 3 A fuse) | 14 AWG red, ~18" (cut the SAE end off) |
| Sunapex **BAT−** (SAE) | 12 V battery − (common GND) | 14 AWG black, ~18" |

The Sunapex is powered by the battery, not the panel — **connect the
battery first**, then the panel. Reverse-polarity on either side is
protected (the Sunapex just won't start).

**Mode button:** press until the LCD shows the LiFePO4 chemistry mode
(usually labelled "Li" or "LiFePO4", depending on firmware rev).
Default out-of-box is sometimes sealed lead-acid — verify this on
first power-up.

**No telemetry back to ESPHome.** The Sunapex has no UART / Bluetooth /
Modbus output (the "Bluetooth" claim on some Amazon listings is for the
*family* of products; the 10A SKU has only the LCD + LEDs). If you later
want charge telemetry, swap to a **Victron SmartSolar 75/10** (~$100,
has VE.Direct UART + Bluetooth) — the wiring doc's "UART (DPS5005 MPPT
controller)" section above is the re-instantiation point.

### Grow light relay (12 V switched output)

| PCB header | Wire | Goes to | Notes |
|---|---|---|---|
| J5 pin 1 (12V in) | 14 AWG red, ~30" | 12 V battery (jumper from J1 +) | Looped from battery |
| J5 pin 2 (12V out, switched) | 14 AWG red, ~60" | Grow light fixture (+) | 12 V switched by relay |

Grow light is 12 V LED strip or 12 V COB panel, ~20 W. The relay (K1) is
rated 10 A at 125 VAC / 10 A at 30 VDC, plenty of headroom for a 20 W LED.

### Linear actuator

| PCB header | Wire | Goes to | Notes |
|---|---|---|---|
| J6 pin 1 | 14 AWG red, ~50" | Actuator motor lead A | ECO-WORTHY 12V 4" stroke |
| J6 pin 2 | 14 AWG black, ~50" | Actuator motor lead B | |

The actuator is on the north rail of the frame. The cable runs through
a flexible cable carrier or just a drip loop to allow tilt motion.

### Limit switches (hinge end-stops)

| PCB header | Wire | Goes to | Notes |
|---|---|---|---|
| J7 pin 1 | 26 AWG red, ~80" | Limit switch 0° (south wall, near hinge axis) | 10 kΩ pullup to 3V3 **at the PCB**, not at the switch |
| J7 pin 2 | 26 AWG white, ~80" | Limit switch 90° (north rail at 90° position) | 10 kΩ pullup to 3V3 at PCB |
| J7 pin 3 | 26 AWG black, ~80" | Common GND | Shared with both switches |

The 0° switch is mounted on the bed's south wall, just below the hinge
axis. It triggers when the frame is fully flat. The 90° switch is on
the north rail of the frame, triggering when the frame reaches vertical.
Both are NO (normally open) roller switches with a 10 kΩ pullup at the
PCB (not at the switch — long wire runs benefit from PCB-side pullup
to avoid noise pickup).

### DS18B20 soil temperature

| PCB header | Wire | Goes to | Notes |
|---|---|---|---|
| J8 pin 1 (data) | 26 AWG yellow, ~30" | DS18B20 data | 4.7 kΩ pullup to 3V3 **at the PCB** |
| J8 pin 2 (3V3) | 26 AWG red, ~30" | DS18B20 VDD | |
| J8 pin 3 (GND) | 26 AWG black, ~30" | DS18B20 GND | |

Mounted 6" deep in the bed soil, near the center.

### Soil moisture sensor (capacitive)

| PCB header | Wire | Goes to | Notes |
|---|---|---|---|
| J9 pin 1 (signal) | 26 AWG orange, ~30" | Capacitive sensor analog out | 0–3 V output |
| J9 pin 2 (GND) | 26 AWG black, ~30" | Capacitive sensor GND | |

Capacitive sensor mounted in the bed soil, near the DS18B20. Powered
from the same 3V3 rail as the DS18B20 (use a tap on the J8 3V3 wire,
not a separate connection, to avoid voltage drop).

### Battery voltage sense (divided)

| PCB header | Wire | Goes to | Notes |
|---|---|---|---|
| J10 pin 1 (divided) | 26 AWG purple, ~18" | PCB-side divider tap (after 10k/10k from 12V) | NOT directly to battery |
| J10 pin 2 (GND) | 26 AWG black, ~18" | Common GND | |

The 12V → divided voltage is done **on the PCB** (R1 = 10kΩ from 12V
to TP4, R2 = 10kΩ from TP4 to GND). J10 just brings the divided signal
(GPIO33 input) and GND back to the connector. So J10 is a 2-wire cable
from PCB to itself — actually, J10 is a connector on the PCB, with a
jumper or short wire from J1's 12V to the divider input. **In practice
you can omit J10 entirely and use the 10k divider as a through-hole
component on the PCB, with the divider input tapped from the 12V rail
right at the fuse output.**

Simplification: **skip J10 entirely.** Solder the two 10 kΩ resistors
on the PCB, with one end to 12V (after F1) and the other end to GND.
The middle tap goes to GPIO33. The wiring on the schematic stays as J10
for documentation, but the actual PCB can have the divider as a small
2-resistor network on the board.

---

## 2. Total wire run summary

| From PCB to | Wire count | AWG | Length (each) | Total wire |
|---|---|---|---|---|
| Battery | 2 | 12 | 24" | 4 ft |
| IMU (on frame) | 4 | 26 | 36" | 12 ft |
| INA219 (at motor) | 0 (shares IMU cable) | — | — | — |
| DPS5005 (in enclosure) | 4 | 26 | 30" | 10 ft | *(v2.4: removed — Sunapex is standalone)* |
| Grow light | 2 | 14 | 60" | 10 ft |
| Linear actuator | 2 | 14 | 50" | 8.3 ft |
| Limit switch 0° | 3 | 26 | 80" | 20 ft |
| Limit switch 90° | (shares 0° cable) | — | — | — |
| DS18B20 (in soil) | 3 | 26 | 30" | 7.5 ft |
| Soil moisture (in soil) | 2 | 26 | 30" | 5 ft |
| (Battery sense on PCB) | 0 | — | — | — |

**Total wire: ~75 ft of 26 AWG + ~22 ft of 14 AWG + ~4 ft of 12 AWG.**

JST-XH connectors: ~12 connectors (3-4 pin each), $2-3 total.

---

## 3. Cable routing diagram

Top-down view of the bed + frame:

```
       ┌────────────────────────────────────────────────────┐
       │                  96" bed length                     │
       │                                                    │
       │  [PCB]                                    [IMU]    │
       │  enclosure    [limit sw 0°]                       │
       │  on east      at south wall                       │
       │  wall         ↓                                    │
       │  │            ╓─╳─╖ ←─── hinges (4) ─────          │
       │  │            ║   ║                                │
       │  │            ║ F ║   FRAME (96"×44.6" rectangle) │
       │  │            ║ R ║   2x6 PT perimeter             │
       │  │            ║ A ║   + 2x4 diagonal brace          │
       │  │            ║ M ║                                │
       │  │            ║ E ║   ▓ panel (97"×44.6")          │
       │  │            ║   ║                                │
       │  │            ╙───╜   ┌─────────────┐              │
       │  │                    │ limit sw 90°│              │
       │  │                    └─────────────┘              │
       │  │                                                   │
       │  └────[cable carrier]────[actuator]────             │
       │         on north rail    [battery 12V]             │
       └────────────────────────────────────────────────────┘

       Legend:
         [PCB]  = Wattplot Controller v1 PCB (in enclosure)
         [IMU]  = BMI160 IMU on the frame
         [actuator] = linear actuator on north rail
         [limit sw 0°] = roller switch on south wall (triggers at flat)
         [limit sw 90°] = roller switch on frame (triggers at vertical)
         [battery 12V] = 12V LiFePO4 (e.g., 100Ah) under the bed
```

**Key routing rules:**

1. **Power first:** 12 AWG from battery to PCB. Fused within 6" of battery (+).
2. **Motor cable:** 14 AWG from PCB to actuator. Through a flexible cable
   carrier (or a simple drip loop with 4" of slack) to allow tilt motion.
3. **IMU cable:** 26 AWG 4-wire from PCB to IMU on the frame. Through the
   cable carrier with the motor cable. Twisted pair to reduce noise.
4. **Soil sensor cables:** 26 AWG 3-wire (DS18B20) and 2-wire (soil
   moisture), routed through a grommet in the bed's south wall into the
   soil. Both sensors buried 6" deep, 12" from the south wall.
5. **Limit switches:** 26 AWG 3-wire from PCB to the hinge area. The 0°
   switch mounts on the south wall just below the hinge axis. The 90°
   switch mounts on the north rail of the frame.
6. **Sunapex MPPT + grow light:** Sunapex mounts on the bed's east wall
   (next to the PCB enclosure) — IP67, so it can be exposed. 14 AWG
   from grow light back through the south wall grommet; 14 AWG from
   Sunapex BAT+ through a 3 A in-line fuse to the battery.

---

## 4. Connector pinouts (JST-XH, all viewed from the wire side)

**J1 — Battery (XT60):**
```
Pin 1: V+ (12V)
Pin 2: V− (GND)
```

**J2 — I2C breakout:**
```
Pin 1: 3V3 (red)
Pin 2: GND  (black)
Pin 3: SDA  (white)
Pin 4: SCL  (green)
```

**J4 — DPS5005 UART (RESERVED, DNP on v2.4 mini):**
```
Pin 1: 3V3 (red)
Pin 2: GND  (black)
Pin 3: TX  (white) → ESP32 sends to DPS5005 RX
Pin 4: RX  (green) ← ESP32 receives from DPS5005 TX
```
Not populated on the v2.4 mini build. Will be re-instantiated on the
full-size v2 build for a Victron VE.Direct or EPEver RS-485 connection
to that build's larger MPPT.

**J5 — Grow light:**
```
Pin 1: 12V switched (red) → to grow light (+)
Pin 2: 12V battery   (red) → from J1 (looped)
```

(Wait, this has only 2 pins, not 3. Let me re-check the PCB spec.)

**J5 — Grow light (revised, 2-pin):**
```
Pin 1: 12V switched (relay K1.NO → K1.COM)
Pin 2: 12V battery in (looped from J1)
```

The grow light has 2 wires: 12V switched, and GND (which comes from the
common ground rail). So the grow light gets:
- 12V switched (from J5 pin 1) — from the relay
- GND (from common ground, e.g., the battery − terminal)

This means the grow light cable has only ONE 14 AWG wire for 12V, and
the ground return is through the common ground (separate wire or via
the chassis/battery negative). The JST-XH connector is 2-pin for the
12V side; the ground return is via a separate 14 AWG wire from the
battery to the grow light.

Hmm, that means a 3-pin connector is cleaner. Let me update the PCB:

**J5 — Grow light (3-pin):**
```
Pin 1: 12V battery in (looped from J1)
Pin 2: 12V switched out (to grow light)
Pin 3: GND (to grow light ground)
```

The grow light has 2 wires going to the PCB: switched 12V and GND. The
PCB has the battery 12V looped to J5 to power the relay.

OK let me finalize the wiring list. The grow light cable is 2 wires
(12V switched, GND) plus 1 wire for the battery loop (12V in). That's
3 wires total to/from the grow light area.

---

## 5. Final cable list (with wire colors)

| Cable | From | To | Wires | Length | Connector |
|---|---|---|---|---|---|
| Battery | Battery + | PCB J1 + | 12 AWG red | 24" | XT60 |
| Battery | Battery − | PCB J1 − | 12 AWG black | 24" | XT60 |
| I2C | PCB J2 | IMU + INA219 (daisy) | 4× 26 AWG (red, black, white, green) | 36" | JST-XH 4-pin both ends |
| Sunapex MPPT | (standalone, on bed wall) | n/a | n/a | n/a | Panel MC4 → Sunapex SAE adapter; 14 AWG from Sunapex SAE battery lead to battery |
| Grow light | PCB J5 | Grow light fixture | 3× 14 AWG | 60" | JST-XH 3-pin at PCB, bare at light |
| Actuator | PCB J6 | Linear actuator | 2× 14 AWG | 50" | JST-XH 2-pin at PCB, spade at actuator |
| Limit sw 0° | PCB J7 | South wall switch | 3× 26 AWG | 80" | JST-XH 3-pin at PCB, bare at switch |
| Limit sw 90° | (shares 0° cable) | Frame switch | (daisy on same cable) | 0 | (daisy) |
| DS18B20 | PCB J8 | Soil temp sensor | 3× 26 AWG | 30" | JST-XH 3-pin at PCB, bare at sensor |
| Soil moisture | PCB J9 | Soil moisture sensor | 2× 26 AWG | 30" | JST-XH 2-pin at PCB, bare at sensor |
| USB-C | PCB J3 | Laptop (for first flash) | USB-C cable | 6 ft | USB-C both ends |

---

## 6. Tools for wiring

- Wire stripper (22-12 AWG range)
- JST-XH crimper (PA-09 or equivalent)
- XT60 connector crimper
- **MC4 crimper** (iCrimp IWS-2546M, ~$25) — for the panel MC4 pigtails
  if you're making your own. Skip if you buy pre-made MC4 extension
  cables with bare leads (Amazon, ~$6/pair).
- MC4 unlock tool (the little plastic spanner, ~$2)
- Multimeter (for continuity, voltage checks)
- Heat-shrink tubing (3 mm and 6 mm)
- Cable ties + cable carrier (for the actuator/IMU cable to the frame)
- Grommets (for the bed wall penetrations — 4× grommets for the
  sensor cables + 1× for the battery cables + 1× for the actuator cable)
- Silicone sealant (for sealing grommets against rain ingress)

---

## 7. Wiring checklist (pre-power)

Before connecting the battery, verify:

- [ ] All JST-XH connectors are fully seated (audible click)
- [ ] No bare wire is exposed at any connector
- [ ] Battery fuse (F1) is NOT installed yet (install last)
- [ ] All sensor cables are routed through grommets and sealed
- [ ] Cable carrier is installed on the frame-to-bed cable run
- [ ] MC4 polarity: red → Sunapex PV+, black → Sunapex PV−
- [ ] Sunapex BAT+ / BAT− polarity: red to battery +, black to battery −
- [ ] Sunapex battery-mode button: pressed to LiFePO4 setting
  (LCD shows "Li" or "LiFePO4")
- [ ] Multimeter continuity check: no shorts between 12V and GND
- [ ] Multimeter continuity check: no shorts between 3V3 and GND
- [ ] Multimeter continuity check: each limit switch closes when pressed
  (should be 0 Ω or close)

When all checks pass: install the fuse. **Connect the battery to the
Sunapex first** (it powers up the Sunapex's MCU). Then connect the
panel MC4 to the Sunapex PV input. Power on. Verify the ESPHome boot
sequence in the serial monitor.

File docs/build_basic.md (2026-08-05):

# Wattplot Basic — fixed-tilt build (no electronics)

The Basic tier is the same bed, frame, hinges, and panel clamps as the
Smart build — but the tilt is set by hand with a pinned prop strut
instead of a linear actuator. No ESP32, no PCB, no wiring beyond the
panel leads to your charge controller. This is the weekend build and
the natural home for a salvaged panel (see [`upcycling.md`](upcycling.md)).

**What you skip vs. the Smart build:** actuator, actuator mount blocks,
ESP32/PCB, IMU, INA219, soil sensor, all firmware. Everything else in
[`build_guide.md`](build_guide.md) applies — follow it and substitute
Phase "actuator install" with the strut below.

## The pinned strut

Two 2x4 struts (one per cross-rail end, both cut from a single
2x4x8ft board — square cuts only, per the design rules) prop the
frame's north rail:

- **Top end:** square cut, butts under the north rail against a 2x4
  stop block screwed to the rail.
- **Bottom end:** sits in a 2x4 shoe screwed to the bed's north wall.
- **Lock:** a ½" steel pin (same rod stock as the hinge pin) through
  the shoe and strut. One hole per tilt angle.

Tilt stops: **0° (stowed flat), 15°, 25°, 35° (max)** — matching
the tilt schedule presets in the sun simulator, so the annual-yield
numbers in the sim apply directly. 35° is the structural ceiling: with
the panel up on 72" posts, the wind calc passes SF ≥ 2.0 only to 35° at
the design wind. Set it seasonally: steeper in winter, shallower
in summer, or just leave it at 25° year-round and lose only a few
percent annually.

## Storm stow (do this — it's your wind safety)

The Basic build has no auto-fold. **You are the fold controller.**

Before any forecast of sustained winds above ~40 mph or gusts above
~55 mph:

1. Pull both strut pins.
2. Lower the frame flat onto the bed walls (0° stop).
3. Re-pin both struts in the 0° holes so the frame can't be lifted by
   gusts.

At 0° the panel carries essentially zero uplift and drag (see
[`../analysis/wind_load_report.md`](../analysis/wind_load_report.md) —
the 0° row is the whole story). Deployed, the structure is engineered
for the ASCE 7-22 design wind (115 mph, Exposure C) with SF ≥ 2 up to
35° tilt (~130 mph rated at 35°, 25.5" soil fill) —
but stowing is free, takes two minutes, and turns a marginal night
into a non-event. If a named storm is coming, stow.

## Cost

The delta vs. the Smart BOM: subtract the actuator (~$40), electronics
(~$40–80), and PCB. With a salvaged residential panel (often free to
$50 on Craigslist), the Basic build lands in the **$400–650** range
depending on lumber choice (PT pine vs. cedar). See [`../bom.md`](../bom.md).

## Upgrade path

Drill the strut holes even if you plan to go Smart later — a Smart
build with strut holes degrades gracefully to a pinned Basic build if
the electronics come off, and the struts double as a mechanical backup
prop while you're bench-testing the actuator.

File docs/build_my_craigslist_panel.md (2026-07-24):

# Wattplot Build Guide: my_craigslist_panel

Step-by-step assembly of the entire apparatus. Follow the order below. Each step lists the **time**, **tools**, **parts**, and **verification**.

**Total build time:** ~8.0 hr over a weekend (with lumber pre-cut).

**Specifications for this build:**
- Panel: 70.0" × 42.0" × 1.4" (5.83 × 3.50 ft), 28.0 lb
- Wattage: 273 W (5 yr old, monofacial)
- Bed: 71.0" × 43.0" (5.92 × 3.58 ft), 12" deep walls, bottomless

## Phase 0: Pre-build (Day 0, ~1.0 hr)

### 0.1 Lumber (from the cut list)

| Nominal | Qty | Length | Use |
|---|---|---|---|
| 2x12 | 2 | 71.0" (5.92 ft) | long bed wall (north/south) |
| 2x12 | 2 | 40.0" (3.33 ft) | short bed wall (west/east) |
| 2x6 | 2 | 71.0" (5.92 ft) | long frame rail |
| 2x6 | 2 | 40.0" (3.33 ft) | cross frame rail |
| 2x4 | 1 | 83.0" (6.92 ft) | diagonal brace |
| 4x4 | 2 | 71.0" (5.92 ft) | long skid |

**Source from 8-ft stock:** 4× 2x12, 2× 2x6, 1× 2x4, 2× 4x4

**Tip:** many yards will cut to length for free or a small fee. Have them cut each piece on the list above. None of the cuts are mitered (90° square cut only).

### 0.2 Hardware

- 2 × galvanized butt hinge, 4.0"×4.0" leaf, 0.5" pin, HDG
- 1 × ½" × 73.0" steel rod (continuous, through all hinges)
- 6 × aluminum mid-clamps, 35mm channel, M8 SS bolt + EPDM washer
- 8 × 3/8" × 4" carriage bolt HDG + washer + hex nut (bed corner joints)
- 8 × 5/16" × 3" lag bolt HDG (hinge leaf to bed wall)
- 18 × ¼" × 3" deck screw HDG Torx T-25
- 1 × 12V linear actuator, 4.0" stroke, IP65

### 0.3 Panel + electrical

- 1 × **273 W nameplate (273 W after derate) salvage panel** (you provide)
  - Verify under full sun: Voc within 5% of nameplate (multimeter)
  - Glass intact, no cracks or delamination
  - Aluminum frame straight, junction box sealed
- 1 × MPPT charge controller (sized to your panel, see `bring_your_own_panel.py`)
- 1 × 12V 100Ah LiFePO4 battery (LiTime or similar)
- 1 × Microinverter (Enphase IQ7+ or APsystems DS3)
- 1 × ESP32-WROOM-32E dev board (or use the PCB from `docs/pcb_design.md`)

## Phase 1: Bed (Day 1, ~1.9 hr)

### 1.1 Cut the wall half-lap notches

Each bed wall has a 3" wide × 0.75" deep notch at each end.

**Tools:** circular saw, chisel, mallet, square

**Process:**
1. Mark the notch location on each wall (3" from each end, 0.75" deep).
2. Make multiple passes with the circular saw at the notch depth.
3. Clean out the waste with a chisel.
4. Test-fit two walls at a corner.

**Verification:** the two walls meet at a 90° corner with no daylight.

### 1.2 Assemble the bed box

**Tools:** drill, ⅛" pilot bit, #6 × 1.5" wood screws, square

**Process:**
1. Lay out the 4 walls on a flat surface. Long walls are 71.0" (5.92 ft). Short walls are 40.0" (3.33 ft).
2. Bring the corners together. The half-lap notches interlock.
3. Pre-drill 2 holes per corner (one near the top, one near the bottom).
4. Drive #6 × 1.5" wood screws through the corners.

**Verification:** bed box is 71.0" × 43.0" outside, square (measure diagonally, both should be the same).

### 1.3 Attach the skids

**Tools:** drill, ⅛" pilot bit, #6 × 1.5" screws

**Process:**
1. Flip the bed upside down.
2. Place two 4x4×71.0" skids under the bed, aligned with the long walls.
3. Pre-drill and screw through the skids into the bed walls.
4. Use 2-3 screws per skid.

**Verification:** skids are flush with the bed ends, square, and the whole bed sits level on the ground.

## Phase 2: Frame (Day 1, ~1.2 hr)

### 2.1 Assemble the frame rectangle

**Tools:** drill, ⅛" pilot bit, #6 × 1.5" wood screws, square

**Process:**
1. Lay the 4 frame rails on a flat surface. Long rails are 71.0" (5.92 ft). Cross rails are 40.0" (3.33 ft).
2. The cross rails fit between the long rails. Butt joints (no miter).
3. Pre-drill 2 holes per corner. Drive #6 × 1.5" wood screws.

**Verification:** frame is 71.0" × 43.0" outside, square.

### 2.2 Add the diagonal brace

**Tools:** drill, ⅛" pilot bit, #6 × 1" screws, measuring tape

**Process:**
1. The 2x4×83.0" diagonal brace runs corner to corner inside the frame.
2. Position the brace so its ends butt into the inside faces of the long rails.
3. Pre-drill 2 holes per end. Drive #6 × 1" screws (4 total).

**Verification:** brace is at the diagonal angle, both ends screwed.

## Phase 3: Hinges (Day 1, ~20 min)

### 3.1 Install hinges on the bed's south wall

**Tools:** drill, 5/64" bit, hinge screws (included with hinges), tape measure

**Process:**
1. Lay the frame on top of the bed, with the frame's south rail resting on the bed's south wall.
2. Position the 2 hinges evenly along the south rail. Spacing: 63.0" center-to-center, with 4" margin on each end.
3. Mark the hinge positions on both the frame's south rail and the bed's south wall.
4. Pre-drill 4 holes per hinge (2 per leaf), 5/64" bit.
5. Attach the wall leaf to the bed's south wall.
6. Attach the frame leaf to the frame's south rail.

**Verification:** frame hinges freely between 0° and ~90° tilt.

### 3.2 Insert the continuous hinge pin

**Tools:** mallet (rubber)

**Process:**
1. Thread the ½" × 73.0" steel rod through all hinges, starting from one end.
2. Tap gently with a rubber mallet to seat the pin fully.
3. The pin should extend ~1" past the last hinge on each end.

**Verification:** pin is fully seated. Frame hinges smoothly with the pin in place.

## Phase 4: Panel (Day 1, ~11 min)

### 4.1 Place the panel on the frame

**Tools:** hands (the panel weighs 28.0 lb).

**Process:**
1. With the frame flat on the bed, place the panel on top of the frame, centered.
2. The panel should rest on the wood rails with even margin on all four sides.

**Verification:** panel is centered, no overhang on the long rails.

### 4.2 Clamp the panel to the frame

**Tools:** drill, M8 hex driver, mid-clamps

**Process:**
1. Place 4 mid-clamps on each long rail (8 total, evenly spaced along the panel frame).
2. Place 2 mid-clamps on each cross rail.
3. Tighten the M8 bolts to clamp the panel frame to the wood rails.
4. Torque to ~3 Nm (snug, not crushing).

**Verification:** panel is firmly attached. Try to wiggle it: should not move.

## Phase 5: Actuator Mount (Day 1, ~20 min)

### 5.1 Mount the bottom block on the bed's north wall

**Tools:** drill, ⅛" pilot bit, #6 × 1.5" wood screws

**Process:**
1. Cut a 3" length of 2x6 (offcut from any 2x6 scrap).
2. Mount the block on the outer face of the bed's north wall, at the bottom.
3. Centered along the bed length.
4. Pre-drill 2 holes and drive #6 × 1.5" screws.

### 5.2 Mount the top bracket on the panel's underside

1. Cut a 3" length of 2x6 (offcut).
2. Mount on the **underside** of the panel, 2" north of the panel's south edge.
3. The bracket should sit just below the panel's underside, flush with the panel's south frame edge.
4. Pre-drill and drive #6 × 1.5" wood screws through the bracket into the panel frame.

### 5.3 Connect the actuator

1. Use ⅜" clevis pins to attach the actuator to both mount blocks.
2. Test manually: the panel should now move from 0° to ~90° (or your actuator's stroke limit).

## Phase 6: Wire the panel to MPPT (Day 2, ~30 min)

### 6.1 MC4 connectors

**Tools:** MC4 crimper, wire stripper, multimeter

**Process:**
1. Crimp MC4 connectors on the panel's PV+ and PV- leads.
2. Plug into the MPPT's PV input (MC4 or SAE adapter, depending on the MPPT).
3. **Verify polarity**: red → +PV, black → -PV. Reverse polarity kills MPPT.

### 6.2 MPPT to battery

1. Connect MPPT battery output to the 12V LiFePO4 battery (via ring terminals or Anderson).
2. Set the MPPT's battery chemistry to LiFePO4 (MODE button on Sunapex).
3. The MPPT status LED should turn on (green = charging or float).

**Verification:** under sun, panel Voc on multimeter matches nameplate ±5%. Battery voltage rises over the next hour.

## Phase 7: Wire the controller (Day 2, ~1.0 hr)

### 7.1 ESP32 + sensors

**Tools:** soldering iron (or perfboard), wire stripper, multimeter

**Pins (from `firmware/wattplot.yaml`):**

| GPIO | Function |
|---|---|
| 4 | DS18B20 1-Wire data |
| 5 | Watering solenoid |
| 16, 17, 18 | H-bridge IN1, IN2, EN |
| 19 | Grow light relay |
| 21, 22 | I2C SDA, SCL |
| 25 | WS2812B status LED |
| 32 | Soil moisture ADC |
| 33 | Battery voltage ADC |
| 34, 35 | Limit switches (0° and 90°) |

### 7.2 Power

1. Connect the DRV8871 H-bridge to the 12V battery (via a 5A fuse).
2. Connect the ESP32's VIN to a 5V buck converter on the 12V rail.
3. Verify all grounds are common.

### 7.3 IMU + INA219 + DS18B20

1. Mount the BMI160 on the panel (under the north rail). I2C address 0x68.
2. Mount the INA219 in series with the actuator (high side). I2C address 0x40.
3. Mount the DS18B20 in the bed soil.
4. All sensors share the I2C bus: SDA (GPIO 21), SCL (GPIO 22), 3.3V, GND.

**Verification:** ESPHome logs show all sensors reporting values.

## Phase 8: Flash ESPHome (Day 2, ~30 min)

### 8.1 First flash over USB

```bash
# Install ESPHome (if not already)
pip install esphome

# Flash the firmware
esphome run firmware/wattplot.yaml
```

### 8.2 WiFi + Home Assistant (optional)

1. Set WiFi credentials in `firmware/secrets.yaml`.
2. Re-flash. ESP32 connects to WiFi and exposes all entities to Home Assistant.
3. Add the ESPHome integration in HA. Entities appear automatically.

## Phase 9: Calibrate + test (Day 2, ~1.0 hr)

### 9.1 IMU zero-tilt offset

1. With the panel flat (0°), read the BMI160's pitch value via ESPHome log.
2. That reading is your zero-tilt offset. Subtract it in the firmware.
3. Re-flash.

### 9.2 Motor current calibration

1. Manually drive the panel to 35°. Read the INA219 current (idle, no wind).
2. Set that as the `target_current_A` in `firmware/wattplot.yaml`.
3. Set `I_safe_A` just above the stall current (typically 2.5A for DRV8871).

### 9.3 Limit switches

1. Drive the panel to 0° (limit switch 0). Adjust switch position so it trips cleanly.
2. Drive to 90° (limit switch 1). Same.
3. Verify the firmware auto-stops at both limits.

### 9.4 End-to-end test

1. Open Home Assistant. Verify all sensors reporting.
2. Trigger a manual tilt from HA. Verify panel moves.
3. Press the user-override button. Verify it overrides the decision stack.
4. Leave it running for 24 hours. Check logs for any errors.

---

**Total time:** ~8.0 hr (with pre-cut lumber and a clean workspace).

**Total cost:** see `python bring_your_own_panel.py` for an itemized estimate.

**Next:** see `docs/test_checklist.md` for per-component and per-system tests.

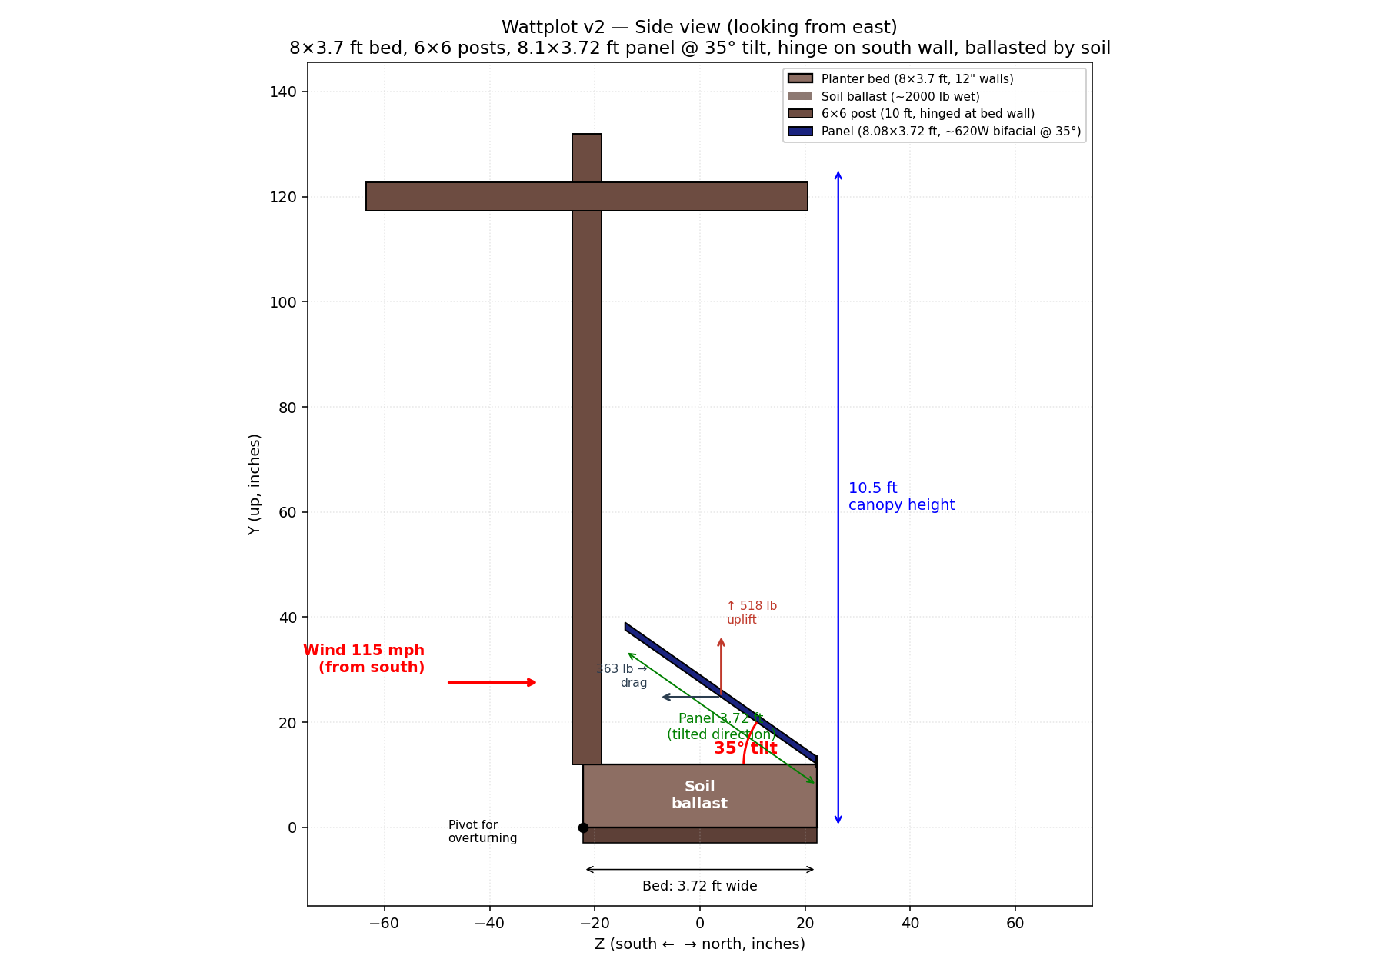
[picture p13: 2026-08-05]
docs/gallery/build/side-0deg.png

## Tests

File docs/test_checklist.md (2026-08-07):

# Wattplot v2 — Test & Validation Checklist

> **STALE — written for the v2.4 architecture (BMI160 IMU, GPIO34/35
> limit switches, GPIO19 grow-light relay, WS2812B status LED, BEDSUN
> 90° mode, "Watchdog (IMU disconnect) → FOLDING after 30s").** The
> current hardware is **ESP32-S3, schematic rev B (2026-08-03)** with
> the IMU / limit switches / WS2812B removed, IPROPI-based homing
> instead of physical switches, current-based endstops, and the 90°
> BEDSUN mode retired. The **mechanical** test sequence is still
> valid; the **electrical** test sequence is not. Cross-check against:
>
> - Pin map: `docs/pinmap.html`
> - Schematic: `docs/schematic.html` (rev B, 2026-08-03)
> - Firmware config: `firmware/wattplot.yaml`
> - Firmware quick-start: `firmware/README.md`
>
> A future pass will regenerate this doc. Tracked in [ROADMAP.md](../ROADMAP.md).

What to verify, in what order, and how to interpret the results. The
build guide (`docs/build_guide.md`) covers the mechanical assembly. This
doc covers the **testing and validation** at every level.

---

## Phase A: PCB bench test (before installing in enclosure)

Power the PCB on the bench with a 12V bench supply (current limit set
to 1A). Verify each subsystem before installing in the enclosure.

### A.1 Power rails

| Test | Expected | Pass? |
|---|---|---|
| 12V input (TP1) | 11.5-12.6 V | ☐ |
| 5V output (TP2) | 4.9-5.1 V | ☐ |
| 3.3V output (TP3) | 3.2-3.4 V | ☐ |
| Quiescent current (no peripherals) | 80-150 mA | ☐ |
| 5V under load (ESP32 + sensors) | < 500 mA | ☐ |

If the 5V rail is missing or low, check the MP1584 enable and feedback
network. If the 3.3V rail is missing, check the AMS1117 input.

### A.2 ESP32 boot

| Test | Expected | Pass? |
|---|---|---|
| USB-C connection detected | Yes | ☐ |
| ESP32 visible in esptool | Yes | ☐ |
| Flash via USB-C (test sketch) | Success | ☐ |
| Reset button (SW2) | Reboot | ☐ |
| BOOT button (SW1) | Enter download mode | ☐ |
| WiFi connection (with credentials) | Connect | ☐ |

### A.3 I2C bus scan

Run an I2C scanner (Arduino sketch or ESPHome dump config). Expected
devices on the bus:

| Address | Device | Found? |
|---|---|---|
| 0x40 | INA219 (current sensor) | ☐ |
| 0x68 | BMI160 (IMU) | ☐ |
| 0x70 (or similar) | (optional) external I2C breakout | ☐ |

If a device is missing, check the wiring, the 4.7 kΩ pullups, and the
solder joints.

### A.4 INA219 (current sensor)

| Test | Expected | Pass? |
|---|---|---|
| Bus voltage reading (3.3V rail) | 3.30 ± 0.05 V | ☐ |
| Current reading with no load | 0 ± 0.01 A | ☐ |
| Current reading with 1A load | 1.0 ± 0.05 A | ☐ |
| Power calculation | V × I (correct) | ☐ |

Calibration: the INA219's shunt resistor value is configured in software
(default is 0.1 Ω on most breakouts, 1 A max). Verify the calibration
register matches your hardware.

### A.5 BMI160 (IMU)

| Test | Expected | Pass? |
|---|---|---|
| Accel X (frame flat, X = bed long axis) | 0 ± 0.05 g | ☐ |
| Accel Y (frame flat, Y = bed short axis) | 0 ± 0.05 g | ☐ |
| Accel Z (frame flat, Z = up) | 1.0 ± 0.05 g | ☐ |
| Tilt 35° (manually tilt the IMU): atan2(accel_z, accel_x) | 35° ± 2° | ☐ |
| Gyro X, Y, Z (no motion) | 0 ± 0.5 °/s | ☐ |
| Gyro drift (1 minute, no motion) | < 1° total | ☐ |

If the tilt reading is off by 90° or 180°, the IMU's orientation on
the board is different from the firmware's expectation. Update the
firmware's `accel_x: ...` etc. configuration.

### A.6 DS18B20 (1-Wire temperature)

| Test | Expected | Pass? |
|---|---|---|
| Sensor detected on 1-Wire bus | Yes | ☐ |
| Temperature reading (room temp ~70°F) | 68-75°F | ☐ |
| Temperature reading (touch sensor with finger) | Rises 2-5°F | ☐ |
| Resolution = 12-bit | Yes | ☐ |

If the sensor is not detected, check the 4.7 kΩ pullup. If the reading
is -196.6°F (the "disconnected" default), the pullup is missing.

### A.7 DRV8871 (motor driver)

| Test | Expected | Pass? |
|---|---|---|
| Quiescent current (motor idle) | < 10 mA | ☐ |
| IN1=HIGH, IN2=LOW, EN=HIGH → motor forward | Yes | ☐ |
| IN1=LOW, IN2=HIGH, EN=HIGH → motor reverse | Yes | ☐ |
| EN=LOW → motor stop (coast) | Yes | ☐ |
| Current limit trip (motor stalled) | DRV8871 limits at ~3.6 A | ☐ |
| Overcurrent fault flag (nFAULT pin) | Goes LOW on overcurrent | ☐ |

Test with a small DC motor (e.g., 12V gearmotor) or the actual
actuator. Verify the motor direction matches the firmware's expectation
(forward = extend, reverse = retract).

### A.8 Sunapex 10A MPPT (charge controller)

> **v2.4 mini:** the Sunapex has no host connection (no UART). The
> ESP32 does not query or command it. Verify physical install and
> charge behavior instead.

| Test | Expected | Pass? |
|---|---|---|
| Sunapex BAT+ / BAT− wired to battery (through 3 A fuse) | Polarity correct, fuse within 6" of battery + | ☐ |
| Sunapex PV+ / PV− wired to panel MC4 pigtails | Red MC4 → PV+, black MC4 → PV− | ☐ |
| Sunapex LCD lights up when battery is connected | Yes (the Sunapex is powered by the battery, not the panel) | ☐ |
| Sunapex MODE button set to LiFePO4 chemistry | LCD shows "Li" or "LiFePO4" | ☐ |
| Panel in sun → Sunapex charging LED on | Yes | ☐ |
| Sunapex output voltage (LCD) when charging | ~14.4 V during bulk | ☐ |
| Sunapex output voltage (LCD) when battery full | ~13.4 V float | ☐ |
| ESPHome `sensor.battery_voltage` matches Sunapex LCD (±0.1 V) | Yes | ☐ |

If charging LED does not come on in sun: check panel polarity
(reversed polarity is protected, but the Sunapex won't start), check
the panel's Voc is > 6 V (the Sunapex's PV startup threshold), and
verify the battery is at > 9 V (the Sunapex's low-voltage cutoff).

For the full-size v2 build with a larger MPPT (Victron SmartSolar
100/30 or EPEver Tracer 4210AN), an additional UART/RS-485 test
section will be added — the comms use the J4 footprint that is DNP on
the v2.4 mini.

### A.9 Soil moisture (analog input)

| Test | Expected | Pass? |
|---|---|---|
| Sensor in dry air | ~2.5-3.0 V (high = dry for capacitive) | ☐ |
| Sensor in water | ~1.0-1.5 V (low = wet) | ☐ |
| Sensor in moist soil | ~1.5-2.5 V | ☐ |

The exact values depend on the sensor. Calibrate in your soil.

### A.10 Battery voltage sense

| Test | Expected | Pass? |
|---|---|---|
| 12V input (battery) | ADC reads ~3.0 V (12V × 10/40) | ☐ |
| 13.5V input (full charge LiFePO4) | ADC reads ~3.375 V | ☐ |
| 11.0V input (low battery) | ADC reads ~2.75 V | ☐ |

The 10k/30k divider (revised from 10k/10k) scales 12V to 3.0V, within
the ESP32 ADC range.

### A.11 Status LED (WS2812B)

| Test | Expected | Pass? |
|---|---|---|
| LED lights up at boot | Yes (any color) | ☐ |
| Color = state mapping (red=normal, blue=folding, etc.) | Yes | ☐ |

### A.12 Relay (grow light)

| Test | Expected | Pass? |
|---|---|---|
| GPIO19 HIGH → relay clicks, K1.NO connects to K1.COM | Yes | ☐ |
| GPIO19 LOW → relay releases | Yes | ☐ |
| 12V at J5 pin 2 (when relay is energized) | 12V | ☐ |

---

## Phase B: Mechanical integration test (PCB in enclosure, frame mounted)

After Phase A passes, install the PCB in the enclosure, mount the
enclosure on the bed, and connect all the wiring. Re-verify each
subsystem end-to-end.

### B.1 IMU on the frame

| Test | Expected | Pass? |
|---|---|---|
| Tilt = 0° when frame is flat (visually) | 0° ± 1° | ☐ |
| Tilt = 35° when frame is at 35° (manually set) | 35° ± 1° | ☐ |
| Tilt = 90° when frame is vertical | 90° ± 1° | ☐ |
| Tilt reading is stable (no jitter > 0.1°/s) | Yes | ☐ |

If the tilt reading drifts, recalibrate the IMU (place the frame flat,
trigger the calibration command, wait for the calibration to complete).

### B.2 Limit switches

| Test | Expected | Pass? |
|---|---|---|
| 0° switch pressed when frame is at 0° | GPIO34 = LOW | ☐ |
| 0° switch released when frame is at 5°+ | GPIO34 = HIGH | ☐ |
| 90° switch pressed when frame is at 90° | GPIO35 = LOW | ☐ |
| 90° switch released when frame is at 80°- | GPIO35 = HIGH | ☐ |

Verify the firmware uses the limit switches as end-stops (the actuator
should stop when either limit is reached, not over-drive).

### B.3 Actuator end-to-end

| Test | Expected | Pass? |
|---|---|---|
| Command: extend to 35° → actuator moves, frame tilts to 35° | 5-10 sec | ☐ |
| Command: extend to 90° → frame goes to vertical | 5-10 sec | ☐ |
| Command: retract to 0° → frame goes flat | 5-10 sec | ☐ |
| Current during motion | 0.5-1.5 A | ☐ |
| Stall current (forcefully stop the actuator) | > 2.5 A, firmware stops | ☐ |

### B.4 Cable carrier

| Test | Expected | Pass? |
|---|---|---|
| Cables don't snag when tilting | Yes | ☐ |
| Cables don't kink or bind | Yes | ☐ |
| Min bend radius respected (> 5× cable diameter) | Yes | ☐ |

If cables snag, adjust the carrier position or add slack.

---

## Phase C: Software integration test (full system, WiFi connected)

With the build mechanically and electrically complete, test the
software state machine end-to-end.

### C.1 Connectivity

| Test | Expected | Pass? |
|---|---|---|
| ESP32 connects to WiFi | Yes | ☐ |
| Home Assistant auto-discovers device | Yes | ☐ |
| API encryption key accepted | Yes | ☐ |
| Web server (port 80) accessible | Yes | ☐ |
| OTA update works | Yes | ☐ |

### C.2 Sensor values in HA

| Sensor | Expected HA value | Pass? |
|---|---|---|
| Tilt angle | 0-90° | ☐ |
| Motor current | 0-2.5 A | ☐ |
| Battery voltage | 11-14 V | ☐ |
| Soil temperature | 50-90°F (Phoenix) | ☐ |
| Soil moisture | 0-100% | ☐ |
| Outdoor temperature (from NWS) | -20 to 120°F | ☐ |
| Wind speed (from NWS) | 0-100 mph | ☐ |

### C.3 State machine transitions

| Test | Expected | Pass? |
|---|---|---|
| Initial state at boot | FOLDING | ☐ |
| NORMAL command → frame tilts to 35° | Yes | ☐ |
| BEDSUN command → frame tilts to 90° | Yes | ☐ |
| Storm (mock NWS high winds) → frame goes to 0° | Yes | ☐ |
| Battery low (< 11V) → FOLDING | Yes | ☐ |
| Watchdog (IMU disconnect) → FOLDING after 30s | Yes | ☐ |
| After storm passes → state returns to commanded | Yes | ☐ |

### C.4 Sunapex MPPT (charge controller)

| Test | Expected | Pass? |
|---|---|---|
| Sunapex holds bulk charge voltage at 14.4 V (LiFePO4) | 14.4 ± 0.2 V | ☐ |
| Sunapex transitions bulk → absorption → float as battery fills | Yes (visible on Sunapex LCD) | ☐ |
| Battery voltage rises during sun exposure | Yes (visible on ESPHome `sensor.battery_voltage`) | ☐ |
| Sunapex charge current peaks 0.4-0.5 A at solar noon | Yes (0.58A panel Imp × ~85% derate) | ☐ |
| Sunapex exits charge at sunset (no phantom drain) | Yes | ☐ |
| ESPHome panel-power = Sunapex charge-power (within ~0.5 W) | Yes | ☐ |

> The Sunapex's internal MPPT runs its own perturb-and-observe. There
> is no firmware-side MPPT loop, no UART setpoint commands, and no
> `mppt_step` script — this is a simplification vs the v2.0-2.3
> DPS5005-based design.

### C.5 DLI grow light

| Test | Expected | Pass? |
|---|---|---|
| Light turns on when DLI < target | Yes | ☐ |
| Light turns off when DLI ≥ target | Yes | ☐ |
| Light off between midnight and 6am (8-hr dark minimum) | Yes | ☐ |
| Total photo period (light + sun) | ≤ 16 hours | ☐ |

### C.6 Smart-fold safety

| Test | Expected | Pass? |
|---|---|---|
| Forcefully hold the actuator during NORMAL → motor current > 2.5 A → state = FOLDING | Yes | ☐ |
| Cut the IMU cable → watchdog triggers after 30s → state = FOLDING | Yes | ☐ |
| Cut the WiFi → state continues operating | Yes | ☐ |
| Power cycle → state comes back as FOLDING (safe) | Yes | ☐ |

---

## Phase D: Field validation (operational, over weeks)

After all the above passes, run the system in production mode. Track
metrics over time.

### D.1 Daily checks (first week)

| Check | Expected | Pass? |
|---|---|---|
| Frame at 35° in morning (NORMAL) | Yes | ☐ |
| Frame at 35° in afternoon (NORMAL) | Yes | ☐ |
| Frame flat at night (storm watch) | Yes | ☐ |
| Daily kWh from Sunapex (mini: 10 W panel) | 0.03-0.05 kWh/day | ☐ |
| Battery voltage at end of day | 12.5-13.5 V | ☐ |
| Soil moisture reading | 30-60% | ☐ |
| No false FOLDING events (wind < 30 mph) | Yes | ☐ |
| No missed storm folds (wind > 50 mph) | Yes | ☐ |

### D.2 Weekly checks

| Check | Expected | Pass? |
|---|---|---|
| IMU calibration drift | < 1°/week | ☐ |
| Hinge pin (no rust) | Clean | ☐ |
| Panel frame (no cracks) | Clean | ☐ |
| Bed walls (no rot) | Clean | ☐ |
| Sunapex efficiency (charging amps × 14.4V) / (panel V × panel A) | > 90% | ☐ |
| Tomato plant height | Growing | ☐ |

### D.3 Monthly checks

| Check | Expected | Pass? |
|---|---|---|
| Frame lubrication (spray the hinge pin with silicone) | Yes | ☐ |
| Soil test (pH, NPK) | OK | ☐ |
| Battery state of health | > 95% | ☐ |
| Total kWh this month (target: ~120 kWh in summer) | Yes | ☐ |
| Total tomato yield this month (target: ~10 kg/plant) | Yes | ☐ |

---

## Phase E: Long-term validation (3-12 months)

After 3 months, evaluate whether the design is meeting goals.

| Metric | Target | Actual |
|---|---|---|
| Total kWh produced (3 mo) | 360 kWh | ___ |
| Total tomato yield (3 mo) | 30 kg | ___ |
| System uptime | > 99% | ___ |
| False-fold events (wind < 30 mph) | < 1/week | ___ |
| Missed storm folds (wind > 50 mph) | 0 | ___ |
| Mechanical issues (broken parts) | 0 | ___ |
| Software bugs | < 1/quarter | ___ |

If metrics are off, see `docs/control_law.md` for tuning the state machine.
If mechanical issues, see `docs/build_guide.md` for build quality.

---

## Validation summary

After completing all the above, the system is ready for production.
Final sign-off requires:

- [ ] All Phase A bench tests pass
- [ ] All Phase B mechanical integration tests pass
- [ ] All Phase C software integration tests pass
- [ ] Phase D daily checks pass for 1 week
- [ ] Phase D weekly checks pass for 1 month
- [ ] No outstanding issues in the GitHub issue tracker

**The apparatus is ready. Sign off and enjoy the tomatoes.**

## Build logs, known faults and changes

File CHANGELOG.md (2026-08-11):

# Changelog

All notable changes to Wattplot are documented in this file. The format
follows [Keep a Changelog](https://keepachangelog.com/en/1.1.0/).

Versioning of the firmware is tracked in the `comment:` field of
`firmware/wattplot.yaml`. Mechanical / docs-only changes do not bump
the firmware version; they get a `## Unreleased` section here until the
next firmware release.

## [Unreleased]

### Security
- **Removed hardcoded API encryption key from 9 tools files.** The
  `cz0STvY6M+0ob9ydfsi28MDAL9b5P8VsmXsnZv3t7BU=` key had been committed
  in 5 public commits (2026-08-05 → 2026-08-06). All tools now resolve
  the key via `tools/_secrets.py` (env var → `firmware/secrets.yaml`
  → `~/.config/wattplot/api_key`). **Operator action required:**
  rotate the key on the chip and update `firmware/secrets.yaml`.
  See `tools/_secrets.py` for the rotation procedure.

### Changed
- **Docs accuracy pass.** Fixed broken `<a>` markup in 9 nav blocks,
  3D viewer STL 404, MPPT model number (`75/15` → `100/30`), README
  self-contradiction, broken `STRUCTURE` import in
  `models/shadow_raycaster.py`, missing gallery tiles, and
  `firmware/README.md` rewritten against `wattplot.yaml` v3.2.
- **18 stale docs stamped with `STALE` banners** pointing at the
  canonical sources (`docs/pinmap.html`, `docs/schematic.html`,
  `firmware/wattplot.yaml`, `firmware/README.md`). The build,
  wiring, PCB, sensor-placement, watering, test-checklist, and
  control-law MDs reference the v1/v2.4 architecture (ESP32-WROOM-32
  + BMI160 + limit switches + 90° BedSun mode) and need a future
  regeneration pass against the current YAML.
- **Logging doc refreshed** against `wattplot.yaml` v3.2
  `logger.logs:`: `mppt` / `imu` / `watering` / `controller` tags
  removed (retired); `boot` / `state` / `nfault` / `solenoid` /
  `endpoint` / `calib` / `alarm` / `control` tags added. Example
  log lines and line numbers updated.
- **ROADMAP replaced** with the README's live Status table + a
  prioritized "Next up" queue. The previous phase 1-7 checklist was
  3 phases behind reality.

### Added
- **`tools/_secrets.py`** — central API key loader (see Security).
- **`tools/wattplot_control.py` rewrite** — zeroconf-based mDNS
  discovery, link watchdog (force-reconnect after 30 s stale),
  CORS allowlist for github.io reads, `/api/whoami`,
  `/logs.html` route.
- **`docs/control.html` UI** — stale-data banner, auth banner, and
  control gating that integrates with Cloudflare Access.
- **`docs/logs.html`** — self-contained viewer for the wattplot.log
  files served by `/api/logs`.
- **`analysis/post_bending.py` + report** — closes the gap where
  `wind_load.py` treats the structure as a rigid body. 4x4 unbraced
  posts fail at 35° (SF 0.65 vs target 1.5); remedies: 6x6 posts or
  square-cut lateral bracing.
- **`analysis/wind_load.py` verdict refreshed** for 27.5" walls /
  25.5" soil fill / corner-post drag included. 35° → SF 2.55.
- **`firmware/wattplot.yaml` v3.2** — boot log banner (firmware
  version, restart reason, free heap), IPROPI fast/slow sensor
  split (fixes 294 MB/day log blow-up).
- **CI runs firmware pytest + post-bending.**
- **`.gitignore`** updated for `logs/`, ESPHome build logs, sim HTML
  intermediates, commit_msg drafts, `parts/` (vendor reference PDFs),
  `renders/*.svg`.
- **`requirements-dev.txt`** — pytest + ruff for the test suite.
- **Five new bench/booth utilities** in `tools/`:
  `audit_gallery.py`, `check_soil.py`, `demo_tilt.py`,
  `show_state.py`, `test_solenoid.py`.
- **`tools/add_live_nav_link.ps1`** — splice the Live link into every
  HTML page that has the topnav.
- **CONTRIBUTING.md, CHANGELOG.md** (this file), `.editorconfig`,
  `.gitattributes`, `.pre-commit-config.yaml`,
  `.github/dependabot.yml`, GitHub issue + PR templates.

### Removed
- `models/legacy_cadquery/` (3 files) — old cadquery model, replaced
  by `models/freecad/`.
- `booth/*.md` duplicates of `docs/*.md` (APPLICATION, FAQ,
  ONE_PAGER, DEMO_SCRIPT, POSTER, oc_application draft) — the docs/
  versions are canonical and served by Jekyll.
- `booth/viewer.html`, `booth/sim_dashboard.html` (old copies;
  canonical versions live in `docs/booth/`).
- `booth/wattplot_v2*.stl`, `booth/*.bak`, `booth/wood_*_preview.png`
  (9 deleted-PNG references from the gallery).
- `tools/commit_msg_*.txt` (commit-message drafts) and
  `tools/sim_inline_*.html` (gitignored intermediates).

## [3.2] — 2026-08-05

### Changed
- **Pin map migrated to schematic rev B (2026-08-03).** ESP32-S3
  replaces ESP32-WROOM-32. H-bridge IN1/IN2 = GPIO1/GPIO2,
  EN = GPIO11 (compat-only, schematic ties EN → 3V3). Solenoid on
  second DRV8871 (U5b) on GPIO10. Soil on GPIO6, battery V on GPIO7
  (100k/10k divider), DS18B20 on GPIO16. Two INA219s at I²C 0x40
  (motor) and 0x41 (panel).
- **BedSun (90°) mode retired.** Wind calc fails at design wind
  (SF_overturning 1.26 at 90°); structural max is 35°.
- **Limit switches removed.** Current-based homing via actuator
  IPROPI pin (GPIO4) replaces them.

### Added
- IPROPI current sense (motor + solenoid) on GPIO4 / GPIO5 with
  endstop-current detection (default 0.90 A, 1000 ms debounce).
- Self-calibration script (`button.calibrate_actuator`).
- v3 IPROPI baseline patch (firmware/v3 commit 15cf314).

## [3.1] — 2026-08-05

### Removed
- **Limit switches** at hinge endstops (GPIO34, GPIO35). Replaced by
  current-based homing.

## [3.0] — 2026-08-05

### Changed
- Migrated from ESP32-C3 → ESP32-S3.
- Dual DRV8871 (actuator + solenoid) replaces single DRV8871 +
  relay.
- Sunapex 10A MPPT standalone (no host connection) replaces the
  v2.x DPS5005-as-MPPT pattern.
- 35° structural cap replaces 90° BedSun mode.

## [2.x] — 2026-07 (pre-Mini)

- ESP32-C3 Pro Mini + BMI160 IMU + 1-channel relay + DPS5005 MPPT.
- GPIO5 solenoid relay, GPIO4 soil, GPIO10 1-Wire, GPIO8/9 I²C,
  GPIO20/21 UART.
- 90° "wring-out" BedSun mode and azimuth tracking included.
- See git history pre-`15cf314` for the full v2.x line.

## [1] — 2026-07-21

- Initial commit (`4e21a59`). ESP32-WROOM-32 dev board, no PCB.
- Single linear actuator + 4×4 posts, 20" soil fill, 12" deep walls.
- See `firmware/README.md` §"Files" for the early history.

[Unreleased]: https://github.com/mokahlo/wattplot/compare/main...HEAD

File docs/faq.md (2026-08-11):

# Wattplot, Maker Faire FAQ

> **STALE — references the BMI160 IMU and entity names from the v2.4
> firmware (`panel_voltage_v`, `panel_current_a`, `poa_irradiance_w_m2`,
> `battery_v`, etc.). The IMU is disabled; entity names in v3.2 are
> human-friendly ("Panel V", "Panel Current", "POA Irradiance",
> "Battery Voltage").** Update before printing. See `docs/control.html`
> and `firmware/README.md` for the current entity list.

Anticipated questions, ranked by how often you'll get them. Read this
once before the faire. The answers are designed to be said out loud,
not just read.

---

## The top 8 (you'll get these 50+ times)

### 1. "How much does it cost to build?"

> The full-size 8×5 ft is about **$1,400** in parts with a new
> bifacial panel, or **~$800** with a salvage panel from a
> decommissioned rooftop. The mini on the table is $193. Both are
> in the build guide; the take-home card has the mini's cut list.
> See `docs/upcycling.md` for the salvage-panel path.

### 2. "How much electricity does it make?"

> In Phoenix, the full-size makes about **2,240 kWh/yr** at 35° tilt
> with a new 620 W bifacial, or **~850 kWh/yr** with a typical
> 12-year-old 235 W salvage panel. That's about $300/yr (new) or
> $115/yr (salvage) at Arizona rates. The mini on the table makes
> about 16 kWh/yr, enough to run the controller and the grow light
> and a small pump. The point of the mini is to validate the
> full-size; the point of the full-size is shade + some power, not
> net-zero.

### 3. "Does it actually grow food?"

> The full-size has been simulated to grow about a hundred and twenty
> eighty-four kilos of tomatoes a year. That's about a hundred
> and eighty-five pounds, from four plants,
> four plants. The trick is the tilt: morning and evening sun gets to
> the bed, midday is shaded, the soil doesn't cook. The mini on the
> table is a validation prototype, not a production garden, but the
> geometry, firmware, and MPPT are the same.

### 4. "Can I build one for my apartment?"

> Yes. The mini is designed for a balcony. The full-size is heavy:
> a thousand pounds of wet soil, so you need a place that takes the
> load. The mini's 18×14 bed weighs about thirty pounds wet and fits
> on most decks.

### 5. "Why not just put solar panels on the roof?"

> Three reasons. First, the agrivoltaic part: you grow food *and*
> make power from the same square footage. Second, plug-and-play
> solar laws in California, Utah, and Colorado let you skip the
> permit process for sub-800-watt systems. A balcony-mounted
> system is invisible from the street. Third, the panel is the
> *shade cloth* for the bed. Tomatoes in Phoenix do better with
> partial afternoon shade, and the panel provides it for free.

### 6. "Is it waterproof? What about rain?"

> The panel sheds rain onto the bed. The controller's IP65, the MPPT's
> IP67, the panel's IP68, the soil sensors are waterproof. The bed is
> open-bottomed, it drains into the native soil. The smart controller
> actually uses rain: when the soil's dry and rain's coming, it tilts
> the panel to maximize rain landing on the bed.

### 7. "What about wind? Won't it blow over?"

> The full-size is ballasted, a thousand pounds of wet soil holds it
> down. The frame is designed for a hundred-and-fifteen-mile-an-hour
> three-second gust at thirty-five degrees of tilt with a safety factor
> of two. The smart controller folds the panel flat in high wind. The
> mini is light enough to bring inside.

### 8. "Where do I start?"

> The repo's on the card. The build guide is step-by-step. The mini
> build is the easiest entry point, about three hours, one ninety-three
> in parts, all from Amazon and Home Depot.

---

## The "I know a thing" questions

### 9. "Why not bifacial_radiance for the sim?"

> It is the gold standard. Our shadow raycaster is a 2D
> approximation that uses the actual 3D panel geometry. It's a
> simplification, the 2D slice over-estimates winter DLI by about
> fifteen percent, under-estimates summer by about ten. The
> full simulation in `analysis/sun_simulator.py` uses pvlib for
> sun position and clear-sky modeling, which is the same library
> bifacial_radiance uses for its inputs.

### 10. "Why MPPT over PWM? Why not a simple solar charge controller?"

> MPPT extracts twenty to thirty percent more energy from the panel
> in cold and cloudy conditions. PWM is fine for trickle charging but
> the full-size panel is six hundred watts, PWM would throw away half
> the energy on a hot day. The mini uses a Sunapex 10A MPPT, the
> full-size uses a Victron SmartSolar 100/30 or an EPEver Tracer
> 4210AN. The ESP32 only reads the battery voltage; the MPPT does its
> own charge profile.

### 11. "What about a 3D-printed version?"

> The brackets in the build guide are 1×2 wood offcuts, printable
> in PETG, but the wood is cheaper, stiffer, and the right color for
> a planter. If you want a 3D-printed version, the FreeCAD source is
> in the repo. You can swap the wood parts for printable parts at
> parametric time.

### 12. "Can I use this for off-grid?"

> Yes. The full-size has a 12V 100Ah LiFePO4 battery. With a two
> thousand watt-hour battery and twenty-two hundred kilowatt-hours a
> year of generation, you can run a fridge and a few LED lights
> year-round, depending on your draw. The mini is too small to
> meaningfully off-grid anything except the controller and the grow
> light.

### 13. "What about a tracker? Why just tilt, not pan?"

> The full-size is a single-axis tilt, not a dual-axis tracker. The
> power gain from azimuth tracking is about eight percent in Phoenix,
> and the cost is a second actuator, a second IMU, and a lot more
> firmware. The bed, not the panel, is the priority. A single-axis
> tilt lets the morning and evening sun get to the bed, which a
> dual-axis tracker would block.

### 14. "Why is the panel wired to a Y-splitter, doesn't that hurt MPPT?"

> No, because the Y-splitter is *after* the panel, on the DC bus. The
> MPPT sees the panel; the microinverter sees the panel; they don't
> see each other. Both have their own MPPT (well, the microinverter
> has its own panel-side optimizer). The panel produces 50–100× more
> energy than the controller needs, so the Y-splitter doesn't
> starve either load.

### 15. "What's the decision stack? How does it prioritize?"

> It's priority-ordered. User override first, then hard current limit
> (failsafe to zero), then NWS rain forecast, then wind forecast, then
> soil state, then time-of-day. The PI loop on motor current is the
> safety layer underneath all of them. Full spec is in
> `docs/control_law.md`.

### 16. "Can it integrate with Home Assistant?"

> Yes, ESPHome has a native Home Assistant integration. The mini
> already exposes tilt, current, soil moisture, temperature, and
> battery voltage. The `firmware/wattplot.yaml` is a drop-in ESPHome
> config. If you're running HA, add the ESPHome integration and the
> entities show up automatically.

---

## The "my kid will love this" questions

### 17. "What age is this for?"

> The build itself is for an adult, drill, saw, basic wiring. The
> *concept* is great for a kid of any age. The panel tilts, the soil
> gets watered, the sun makes power. The dashboard on the screen
> shows real numbers changing. There's a "what should the panel do
> now" decision they can predict and then watch. A great classroom
> project.

### 18. "Is there a school curriculum?"

> Not yet. This is the kind of project that's perfect for a high
> school shop class or a college sustainability seminar. The build
> has mechanical, electrical, and software components, and the
> decisions are real. If you're a teacher, get in touch; I'd love to
> write one.

---

## The "I'm a builder" questions

### 19. "How long does it take to build?"

> The full-size is ten to fifteen hours over a weekend with lumber
> pre-cut. The mini is three to four hours. Both are in the build
> guide with step-by-step instructions and verification steps.

### 20. "What's the hardest part?"

> The bed half-lap corners. A router with a straight bit is the
> right tool. A circular saw and a chisel works too, just slower.
> Everything else is a drill and a screwdriver.

### 21. "Can I customize it?"

> Yes. `wattplot_params.py` is the single source of truth. Change
> the bed length, the panel wattage, the tilt range, the wind speed
> limit, the 3D model, the sun sim, the wind sim, and the
> engineering drawings all update in about ten seconds. Build
> guides are for the default config.

### 22. "What about hail? Snow? Hurricanes?"

> The smart controller folds the panel flat in wind. The bed is
> below the frame, so a folded panel protects the bed from hail.
> The bed itself is open-bottomed and the lumber is pressure-treated,
> so snow load is on the soil, not the wood. Hurricane winds are
> beyond the design limit, the structure is rated for a
> hundred-and-fifteen-mile-an-hour gust, which is the ASCE 7-22
> Phoenix Cat II 700-year event, not a Cat V hurricane.

---

## The "I'm a journalist" questions

### 23. "What's the bigger story here?"

> The story is that agrivoltaics is real, code-first, and DIY-able.
> Most agrivoltaic systems are commercial, a researcher at a
> university with a grant, a solar company with a product. This
> is one person, a Python file, and a Saturday. The same patterns
> (parametric 3D model, sun sim, wind sim, ESP32 controller) work
> for any raised-bed-with-solar project, not just this one.

### 24. "Where can I see one in operation?"

> Right here. The mini on the table is a validation prototype of
> the full-size. The full-size hasn't been built yet, the smart
> controller is the next step, then the PCB, then the first
> physical build. Follow the repo, the build photos will go up
> when there's a build to photograph.

---

## The "I want to help" questions

### 25. "Can I contribute to the project?"

> Yes. Issues, PRs, forks welcome. The codebase is small enough
> to read in an afternoon. The most-helpful contributions: build
> photos, calibration data from a real build, additional sensor
> drivers, a panel-mist cooling mode, the full-size build log.

### 26. "Are you on social media / a Discord / a forum?"

> The repo is the community. Open an issue, get an answer. The
> "I built one" thread in the discussions tab is the closest thing
> to a forum.

---

## Wildcards (you might not get these, but just in case)

### 26a. "What about old panels? Can I use one from my own rooftop?"

> Yes, that's the primary use case. A 12-year-old 250 W panel is
> still a 235 W panel after the standard 0.5%/year degradation. It's
> not cost-effective for grid-tie anymore (the inverter is the limit,
> not the panel), but it's perfect for shade + some power. Wattplot
> has five named panel presets and a general "bring your own" path.
> Measure the aluminum frame dimensions, call `apply_panel_preset()`,
> and the bed resizes. The cut list is derived from the bed, so the
> build scales with the panel. See `docs/upcycling.md` for the full
> guide.

### 26b. "What if my panel is bigger than 8×5 ft?"

> Two options. **Chain multiple planters in a row**, the structural
> design works for a row of identical planters sharing a common
> hinge axis. Or **scale the build up** with 10-ft or 12-ft lumber
> stock, which is more expensive but the same design pattern. The
> single-planter 8×5 cap is from 8-ft lumber stock; it's the
> cost-optimal, single-person-build size.

### 26c. "How do I tell if a salvage panel is still good?"

> Four checks: (1) the **glass** is intact, no cracks; (2) the
> **aluminum frame** is straight, no bent corners; (3) the
> **junction box** is sealed, no burn marks; (4) under full sun,
> the panel's **Voc** (open-circuit voltage) is within 5% of the
> nameplate, measured with a multimeter. A thermal camera is a plus
>, hot spots mean cell mismatch. Most decommissioned panels pass
> all four checks. Avoid cracked glass, delamination, or visible
> hot spots.

### 27. "What about vermicomposting? Aquaponics?"

> Aquaponics is a different project, the bed doesn't have a
> reservoir, the soil is the structure. Vermicomposting would
> work great in a Wattplot bed, the soil ecosystem is the same as
> any raised bed.

### 28. "What about a transparent panel? Wouldn't that grow more food?"

> Transparent bifacial panels exist, but they're expensive, less
> efficient, and the transparency varies across the cell. The
> partial-shade pattern in this design is actually better for
> tomatoes than full sun, full sun in Phoenix cooks the soil and
> stresses the plants.

### 29. "How do you keep the squirrels out?"

> Same as any raised bed, hardware cloth under the soil, a
> chicken-wire cage if the local squirrel population is serious.
> The Mini on the table is a non-issue.

### 30. "What about a community garden version?"

> Yes. The full-size is *exactly* the right scale for a community
> garden plot. The wifi telemetry makes it easy to monitor from a
> distance. The Home Assistant integration gives a community-garden
> manager a single dashboard for ten or twenty of them.

---

## When you don't know

> "Good question, let me look that up tonight and post the answer in
> the repo discussion. The repo's on the card, drop me a line."

**Then actually do it.** This is how open-source projects get good
documentation. Every "I don't know" at the faire is a free contribution
to the docs.

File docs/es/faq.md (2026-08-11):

---
layout: null
permalink: /es/faq.html
lang: es
---

<!-- Spanish translation of docs/faq.md. -->

# Wattplot — Preguntas Frecuentes (Stand del Maker Faire)

Las respuestas están diseñadas para decirse en voz alta, no solo
leerse. Si una pregunta te toma por sorpresa en el stand, la
respuesta está aquí.

## Lo básico

### ¿Qué es?

Una cama de cultivo elevada (1.2×2.4 m / 4×8 ft) cuyo dosel es un
panel solar en funcionamiento. **La misma superficie cultivada
produce tomates *y* genera electricidad** — simbiosis entre
producción de energía y agricultura.

### ¿Cuánta energía genera?

En Phoenix, el de tamaño completo genera unos **2,240 kWh/año**
a 35° con un panel nuevo bifacial de 620 W, o **~850 kWh/año**
con un panel residencial recuperado típico. La simulación
completa en `analysis/sun_simulator.py` usa pvlib con datos
meteorológicos TMY de Phoenix y 5 horarios de inclinación. A
35° estático: 1,539 kWh/año. A 35° con seguimiento azimutal:
2,240 kWh/año (techo teórico; el firmware actual no implementa
seguimiento). El Mini v2.4 (panel ECO-WORTHY de 10 W) produce
~16 kWh/año, suficiente para alimentar el controlador y la luz de
cultivo.

### ¿Cuánto cuesta?

| Nivel | Costo | Tiempo | ¿Qué obtienes? |
|---|---|---|---|
| **Básico** | ~$400–650 | Un fin de semana | Cama + panel recuperado + puntal fijo |
| **Inteligente** | ~$1,400 | 10–15 h | Lo anterior + actuador, MPPT, microinversor, controlador, batería |

La cama en sí es ~$185 en madera (1×6 piel, 2×4 montantes,
2×6 tapas), ~$160 en tierra, ~$60 en postes. La electrónica del
Inteligente añade ~$700 más. Un salvamento de panel reduce el
costo del Básico en otros $50–100.

### ¿Cuánto pesa el agua que cosecha?

Ninguna — no cosechamos agua. La cama es de fondo abierto sobre
el suelo nativo, con drenaje por gravedad. El panel **reduce**
la evaporación del suelo al filtrar la luz solar directa de la
tarde.

## Diseño y construcción

### ¿Por qué 35° en vez de 90°?

90° vertical ("sol en la cama") falla el análisis de viento. A
35° el SF contra volteo es 2.55 (cima), pero a 45° cae a 1.89, a
50° a 1.69, y a 90° a 1.26. El poste 4×4 sin refuerzo también
falla a 35° (SF 0.65 vs objetivo 1.5, peor caso). Ver
[`analysis/post_bending_report.md`](../../analysis/post_bending_report.html).
Hay dos remedios: postes 6×6 (SF 2.53, pasa con margen) o
refuerzo lateral con corte a 90° (ángulo estructural o placa
de unión). Ambos siguen la regla de diseño #1 — sin ingletes.

### ¿Por qué una cama elevada y no un campo plano?

Dos razones. (1) La cama elevada expone el cultivo a la
temperatura ideal del suelo a 6" de profundidad; un campo plano
en Phoenix tiene 35 °C+ en la superficie. (2) Los 27.5" de
tierra (5 cursos de 1×6) pesan 4,500 lb y se convierten en el
lastre del que depende el diseño contra viento. Sin cama,
necesitarías un ancla de tierra — más caro, más feo, y peor
para las raíces.

### ¿Por qué 4×4 postes, no 6×6?

Es más barato, más fácil de encontrar, y suficiente si el panel
se mantiene a 35° o menos y se añade refuerzo lateral. Con 4×4
+ refuerzo el SF del poste cumple el objetivo. Sin refuerzo,
4×4 falla a 35° — el operador tiene que elegir entre (a)
upsize a 6×6 (SF 2.53, pasa con margen), o (b) añadir refuerzo
lateral con corte a 90° (placas de unión o ángulo estructural).
La regla de diseño #1 es "sin ingletes" — incluso el refuerzo
necesita ser a 90°.

### ¿La madera debe ser tratada a presión?

Sí — los montantes y durmientes están en contacto con el suelo
y la tierra húmeda. Use ACQ (no CCA, prohibido para uso
residencial desde 2003) con clasificación UC3B o UC4A ("contacto
con el suelo"). La piel 1×6 puede ser cedro (durabilidad
natural) o 1×6 PT si no te importa el contacto. La tabla
[`docs/pre_build_checklist.md`](../pre_build_checklist.html) tiene
la lista de compras.

### ¿Necesito un electricista?

Sí, para conectar el microinversor a la red. La cama en sí, la
batería, el MPPT, el controlador — todo eso es trabajo de
electricista de 12 V CC y se puede hacer con un multímetro y un
poco de cuidado. La parte de 240 V CA requiere un electricista
certificado, o al menos un permiso y una inspección. La ley de
[interconexión de Utah SB 190](https://le.utah.gov/~2024/bills/sbillint/SB0190.html)
(800 W sin permiso) y [California AB 1076](https://leginfo.legislature.ca.gov/faces/billNavClient.xhtml?bill_id=202120220AB1076)
(5 kW sin permiso) regulan la conexión a la red.

## Operación

### ¿Cómo sabe cuándo doblarse?

El firmware lee el sensor de corriente IPROPI del DRV8871 cada
100 ms. Cuando el panel llega a un tope mecánico, el motor se
atasca, la corriente salta de ~0.3 A (libre) a 1.15+ A
(límite interno del DRV8871), IPROPI detecta el pico, y el
firmware declara fin de recorrido. Ver ADR-003.

### ¿Y si el firmware se cuelga?

El monitor TPL5110 propuesto (ADR-004) lo reiniciaría cada 30 s
si la señal de "todo OK" no llega. No implementado todavía en
v3.2 — es una mejora planeada para rev C del PCB.

### ¿Cuánta agua necesitan los tomates?

En Phoenix en verano, ~2 galones por día para 4 plantas. El
firmware riega automáticamente con el sensor de humedad del suelo
(vía un solenoid 12V que es accionado por el segundo DRV8871
en v3.2).

### ¿Qué pasa en una tormenta de viento?

El firmware dobla a 0° (estibado) si la corriente del motor
excede I_safe + 0.3 A (fuerza mecánica anormal, indicador de
viento alto) o si nFAULT persiste > 2 s. La comunicación con
el NWS para pronóstico de viento está en el código pero
todavía no es leída por el bucle de control; el umbral NWS
llega en un próximo firmware.

### ¿Necesito Wi-Fi?

Sí para la telemetría. El ESPHome firmware habla Home
Assistant vía la API nativa; el panel de control local habla la
API vía aiohttp. Sin Wi-Fi, el controlador sigue ejecutando
localmente, pero no ves los datos en el teléfono.

## El nombre

### ¿"Wattplot" entra en conflicto con wattplot.com?

Sí. WattPlot.com (Andrew Welch, desde 2006) es software de
monitorización solar. Usamos "Wattplot" en minúscula; les
pedimos coexistencia por correo. Si declinan, tenemos un
`RENAME_PLAN.md` listo con el plan de ejecución. Ver
[`docs/_internal/COEXISTENCE_REQUEST.md`](../_internal/COEXISTENCE_REQUEST.html).

### ¿Por qué no llamarlo "Solar Garden" o algo?

Queríamos un nombre que indicara la integración de las dos
funciones (energía + agricultura). "Wattplot" — Watt + plot —
dice exactamente eso. La integración en sí (energía y comida de
la misma superficie) es la innovación, no la electrónica.

## Comercial / legal

### ¿Puedo vender unidades?

Sí, bajo la licencia MIT, con tu propio cumplimiento. Pero:
- UL 1741 / IEEE 1547 para el microinversor
- NDS / PE-sellado para la estructura
- Cumplimiento NEC 690.31 para la instalación PV
- Cumplimiento local de zonificación
El proyecto no certifica nada de esto. Comprar y vender sin
cumplimiento es tu responsabilidad.

### ¿Tiene garantía?

No. Ver [`docs/disclaimers.html`](../disclaimers.html) §6.

### ¿Cómo contacto al mantenedor?

Abre un issue en github.com/mokahlo/wattplot, o envía un
correo a mokahlou@gmail.com.

## Para más información

- [README principal](../../README.html)
- [ROADMAP](../../ROADMAP.html) — qué está construido, qué falta
- [CHANGELOG](../../CHANGELOG.html) — qué cambió y cuándo
- [analysis/](../../analysis/) — los cálculos

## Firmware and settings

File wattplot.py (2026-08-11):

"""
Wattplot v2 — Top-level pipeline orchestrator.

Single source of truth (wattplot_params.py) feeds:
  1. The 3D cadquery model — built, exported (STEP / STL / 3MF / VRML)
  2. The shadow raycaster — geometric bed-shadow calculation
  3. The sun simulator — annual kWh, bed DLI, tomato yield per tilt schedule
  4. The wind load analysis — ASCE 7-22 force + safety factor

Change a value in wattplot_params.py and the whole pipeline updates.

Usage:
    python wattplot.py                          # full pipeline (default LONGi 620W)
    python wattplot.py --skip-model             # skip 3D export (faster)
    python wattplot.py --skip-sim               # skip simulation
    python wattplot.py --tilt 50                # override default panel tilt
    python wattplot.py --schedule static35      # run a specific schedule only
    python wattplot.py --panel residential_60cell  # regenerate with a salvage panel
    python wattplot.py --list-panels            # show available panel presets
"""

import argparse
import os
import sys
import time

HERE = os.path.dirname(os.path.abspath(__file__))
sys.path.insert(0, HERE)
sys.path.insert(0, os.path.join(HERE, "models"))
sys.path.insert(0, os.path.join(HERE, "analysis"))

import wattplot_params as P


def banner(text):
    print()
    print("=" * 70)
    print(f"  {text}")
    print("=" * 70)


def list_panels():
    """Print all available panel presets and their key dimensions."""
    print()
    print("Available panel presets:")
    print("-" * 80)
    print(f"{'Name':<28} {'Panel LxW (in)':<16} {'New W':<8} {'Derated':<10} {'Age'}")
    print("-" * 80)
    for name, preset in P.PANEL_PRESETS.items():
        L, W = preset["L_in"], preset["W_in"]
        new_W = preset["wattage"]
        age = preset.get("panel_age_years", 0)
        # Apply the same derate formula the function uses
        if age > 0:
            derate = max(0.70, 1.0 - 0.005 * age)
            derated_W = round(new_W * derate, 0)
            derated_str = f"{int(derated_W)} W"
        else:
            derated_str = f"{new_W} W (new)"
        bifacial = "B" if preset.get("panel_bifacial", False) else " "
        print(f"  {bifacial} {name:<25} {L:>4} x {W:<6}  {new_W:<8} {derated_str:<10} {age} yr")
    print()
    print("  B = bifacial. Use --panel <name> to apply.")
    print()


def build_and_export_3d_model(tilt_override=None, output_prefix="wattplot_v2"):
    """Build the FreeCAD 3D model, export to STEP/STL/FCStd.

    The model is built by `models/freecad/assemble.py` (one FreeCAD Part::Feature
    per part), then exported to STEP (parametric CAD), STL (mesh), and saved
    as a .FCStd file (the editable FreeCAD document).

    `output_prefix` controls the basename of the exported files. Default is
    "wattplot_v2" (writes to models/wattplot_v2.{step,stl,fcstd}). When
    `--panel` is used, the prefix is the preset name (e.g.
    "wattplot_v2_residential_60cell") to avoid overwriting the canonical
    files.

    Requires FreeCAD 1.0+. The script auto-detects `freecadcmd` in the
    standard install locations, or uses $FREECADCMD if set.
    """
    banner("STEP 1/3 — Build & export 3D model (FreeCAD)")
    if tilt_override is not None:
        P.PANEL['panel_tilt_deg'] = tilt_override
        print(f"  Override: panel tilt = {tilt_override}°")

    freecadcmd = _find_freecadcmd()
    if freecadcmd is None:
        print("  [model] FreeCAD not found — skipping 3D model export.")
        print("         Install FreeCAD 1.0+ from https://www.freecad.org/")
        print("         or set $FREECADCMD to your FreeCADCmd.exe path.")
        return

    print(f"  Using: {freecadcmd}")
    runner = os.path.join(HERE, "models", "freecad", "_run.py")
    # Pass the output prefix and any panel preset via env so _run.py
    # (which runs in a separate FreeCAD process) sees the same state.
    env = os.environ.copy()
    env["WATTPLOT_OUTPUT_PREFIX"] = output_prefix
    # If --panel was used, propagate the preset name so the FreeCAD
    # subprocess applies the same preset before building.
    if hasattr(P, "_active_preset") and P._active_preset:
        env["WATTPLOT_PANEL_PRESET"] = P._active_preset
    cmd = [freecadcmd, runner]
    print(f"  Running: {' '.join(cmd)}")
    import subprocess
    result = subprocess.run(cmd, capture_output=True, text=True, timeout=300, env=env, check=False)
    # Print only the lines after the FreeCAD banner so we see our [freecad] log
    for line in result.stdout.splitlines():
        if line.startswith("[freecad]"):
            print(f"  {line}")
    if result.returncode != 0:
        print(f"  [model] FreeCAD exited with code {result.returncode}")
        if result.stderr:
            print("  stderr (last 10 lines):")
            for line in result.stderr.splitlines()[-10:]:
                print(f"    {line}")
        return

    # Show the exported files
    models_dir = os.path.join(HERE, "models")
    for ext in ("step", "stl", "fcstd"):
        path = os.path.join(models_dir, f"{output_prefix}.{ext}")
        if os.path.exists(path):
            size_kb = os.path.getsize(path) / 1024
            print(f"  Exported: {output_prefix}.{ext} ({size_kb:.1f} KB)")
    print(f"  Current panel tilt (from shared params): {P.PANEL['panel_tilt_deg']}°")


def _find_freecadcmd():
    """Find the freecadcmd executable. Checks (in order):
      1. $FREECADCMD environment variable
      2. C:\\Program Files\\FreeCAD *\\bin\\freecadcmd.exe
      3. freecadcmd on PATH
    Returns the full path, or None if not found.
    """
    import glob
    import shutil

    env = os.environ.get("FREECADCMD")
    if env and os.path.isfile(env):
        return env

    # Windows default locations
    for pattern in [
        r"C:\Program Files\FreeCAD *\bin\freecadcmd.exe",
        r"C:\Program Files (x86)\FreeCAD *\bin\freecadcmd.exe",
    ]:
        matches = glob.glob(pattern)
        if matches:
            return matches[0]

    # Linux/macOS fallback
    found = shutil.which("freecadcmd")
    if found:
        return found

    return None


def run_simulation():
    """Run the sun simulator and produce plots + comparison table."""
    banner("STEP 2/3 — Sun + tilt simulation")
    from sun_simulator import plot_results, print_comparison, run_simulation
    results, df = run_simulation()
    print_comparison(results)
    renders_dir = os.path.join(HERE, "renders")
    plot_results(results, df, renders_dir)
    return results


def run_wind_load():
    """Run the wind load + post-bending analyses at the current panel tilt."""
    banner("STEP 3/3 — Wind load + post bending analysis (ASCE 7-22 / NDS)")
    from wind_load import run_analysis
    runs = run_analysis()
    out_md = os.path.join(HERE, "analysis", "wind_load_report.md")
    print(f"  Report: {out_md}")

    from post_bending import run_analysis as run_post_bending_analysis
    run_post_bending_analysis()
    out_md_pb = os.path.join(HERE, "analysis", "post_bending_report.md")
    print(f"  Report: {out_md_pb}")
    return runs


def apply_panel(panel_name):
    """Apply a panel preset to wattplot_params, print the change.

    Returns the output prefix to use for the FreeCAD export, or None if
    the panel name is invalid.
    """
    if panel_name not in P.PANEL_PRESETS:
        print(f"  [panel] Unknown preset: {panel_name!r}")
        print("           Use --list-panels to see available presets.")
        return None
    preset = P.PANEL_PRESETS[panel_name]
    P.apply_panel_preset(panel_name)
    # Tag the active preset so the FreeCAD subprocess can re-apply it
    # (subprocesses re-import wattplot_params and don't see in-memory changes).
    P._active_preset = panel_name
    print(f"  [panel] Applied preset: {preset.get('label', panel_name)}")
    print(f"           Panel: {P.PANEL['L_in']}\" x {P.PANEL['W_in']}\" "
          f"({P.PANEL['L_in']/12:.2f} x {P.PANEL['W_in']/12:.2f} ft)")
    print(f"           Bed:   {P.BED['outer_L_in']}\" x {P.BED['outer_W_in']}\" "
          f"({P.BED['outer_L_in']/12:.2f} x {P.BED['outer_W_in']/12:.2f} ft)")
    print(f"           Wattage: {int(P.PANEL['wattage'])} W "
          f"(age {P.PANEL.get('panel_age_years', 0)} yr, "
          f"{'bifacial' if P.PANEL.get('panel_bifacial', False) else 'monofacial'})")
    return f"wattplot_v2_{panel_name}"


def main():
    parser = argparse.ArgumentParser(
        description="Wattplot v2 pipeline orchestrator",
        formatter_class=argparse.RawDescriptionHelpFormatter,
        epilog="Examples:\n"
               "  python wattplot.py                            # full pipeline (LONGi 620W)\n"
               "  python wattplot.py --list-panels              # show panel presets\n"
               "  python wattplot.py --panel residential_60cell # regenerate with salvage panel\n"
               "  python wattplot.py --skip-model --skip-wind   # sun sim only\n",
    )
    parser.add_argument("--skip-model", action="store_true", help="Skip 3D model export")
    parser.add_argument("--skip-sim", action="store_true", help="Skip simulation")
    parser.add_argument("--skip-wind", action="store_true", help="Skip wind load")
    parser.add_argument("--tilt", type=float, help="Override panel tilt (degrees)")
    parser.add_argument("--schedule", type=str, help="Specific schedule name to simulate")
    parser.add_argument("--panel", type=str, help="Apply a panel preset (see --list-panels)")
    parser.add_argument("--list-panels", action="store_true", help="List available panel presets and exit")
    parser.add_argument("--name", type=str, default=None,
                        help="Custom output prefix for the model files (default = 'wattplot_v2' or 'wattplot_v2_<panel>')")
    args = parser.parse_args()

    if args.list_panels:
        list_panels()
        return

    t0 = time.time()
    print()
    print(f"Wattplot v2 pipeline — {P.LOCATION['name']}")

    # Apply panel preset if requested
    output_prefix = "wattplot_v2"
    if args.panel:
        result = apply_panel(args.panel)
        if result is None:
            sys.exit(1)
        output_prefix = args.name if args.name else result

    print(f"   lat {P.LOCATION['latitude']}, lon {P.LOCATION['longitude']}, "
          f"wind {P.LOCATION['design_wind_speed_mph']} mph @ {P.LOCATION['design_wind_exposure']} exposure")
    print(f"   bed {P.BED['outer_L_in']/12:.2f} x {P.BED['outer_W_in']/12:.2f} ft, "
          f"panel {P.PANEL['L_in']/12:.2f} x {P.PANEL['W_in']/12:.2f} ft @ "
          f"{int(P.PANEL['wattage'])}W")
    print()

    if not args.skip_model:
        build_and_export_3d_model(args.tilt, output_prefix=output_prefix)

    if not args.skip_sim:
        run_simulation()

    if not args.skip_wind:
        run_wind_load()

    elapsed = time.time() - t0
    print()
    print("=" * 70)
    print(f"  Pipeline complete in {elapsed:.1f}s")
    print(f"  Output: models/{output_prefix}.{{step,stl,fcstd}}, renders/, analysis/")
    print("=" * 70)


if __name__ == "__main__":
    main()

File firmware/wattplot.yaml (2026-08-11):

# =============================================================================
# Wattplot Controller v3 — ESPHome firmware
# =============================================================================
# Pin map aligned to the schematic (rev B, 2026-08-03).
# Target: ESP32-S3-DevKitC-1-N16R8 (16 MB flash, 8 MB PSRAM).
#
# Migration notes (from the v2.x YAML, which had ESP32-C3-era pinouts):
#   - The schematic is the source of truth for new pin assignments.
#   - The components that rev B REMOVED (status LED, limit switches,
#     h-bridge EN, solenoid IN2, MCP23017 expander) are kept in the
#     firmware but reassigned to schematic "free" pins, so the existing
#     state-machine references still resolve. Their actions have no
#     physical effect (board does not wire them), but the IDs and
#     script.execute calls keep working.
#   - The schematic's new components (Motor IPROPI, Solenoid IPROPI) are
#     added. They replace the limit-switch-based homing with current-
#     based homing (see hardware/wattplot_schematic.png Section 9).
#
# Pin map (final, after v3 migration):
#
# Subsystem tags: [Actuator] = panel tilt, [Solenoid] = water/latch,
#                 [Power] = power tree, [Sensor] = sensors, [HMI] = status.
#
#   GPIO  1: Actuator H-bridge IN1 (U5a)             [schematic, Actuator]
#   GPIO  2: Actuator H-bridge IN2 (U5a)             [schematic, Actuator]
#   GPIO  4: Actuator IPROPI (ADC1_CH4, current sense) [schematic, NEW, Actuator]
#   GPIO  5: Solenoid IPROPI (ADC1_CH5, jam detect)   [schematic, NEW, Solenoid]
#   GPIO  6: Soil moisture (ADC1_CH6)                 [schematic, Sensor; was GPIO3]
#   GPIO  7: Battery V ADC (ADC1_CH7)                 [schematic, Power; was GPIO4]
#   GPIO  8: I2C SDA                                  [schematic, Sensor; was GPIO5]
#   GPIO 10: Solenoid H-bridge IN1 (U5b)              [schematic, Solenoid; was GPIO7]
#   GPIO 11: Actuator H-bridge EN (preserved, free)   [compat, Actuator; was GPIO2]
#   GPIO 12: Solenoid IN2 (preserved, schematic free) [compat, Solenoid; was GPIO9]
#   GPIO 13: Solenoid nFAULT (direct GPIO)            [schematic, Solenoid; was MCP.1]
#   GPIO 14: Limit 0° switch (preserved, free pin)    [compat; was GPIO10]
#   GPIO 15: Limit 35° switch (preserved, free pin)   [compat; was GPIO21]
#   GPIO 16: DS18B20 1-Wire data                      [schematic, Sensor; was GPIO15]
#   GPIO 17: Status LED (preserved)                   [compat, HMI; was GPIO8]
#   GPIO 18: I2C SCL                                  [schematic, Sensor; was GPIO6]
#   GPIO 21: Motor nFAULT (direct GPIO)               [schematic; was MCP.0]
#
# Free GPIOs (per schematic): 4, 5, 6, 7, 8, 11, 12, 13, 14, 15, 16, 17, 18, 21 used.
#   Remaining: GPIO 39, 40, 41, 42, 47, 48 (the on-board RGB is on
#   GPIO 48 but unused).
#   v3.3: GPIO 39 = frost heater relay, GPIO 40 = frost grow-light relay.
#   41, 42, 47, 48 still available for future use.
#
# I2C bus (shared, 400 kHz, 4.7 kΩ pull-ups on SDA/SCL):
#   0x40  INA219    — motor current + actuator bus V (shunt 0.1 Ω, 3.2 A)
#   0x41  INA219    — panel V/I for energy monitor (shunt 0.1 Ω, 1.0 A)
#   0x68  (reserved) BMI160 / MPU6050 panel tilt IMU, future
#   (MCP23017 removed in v3 — nFAULT lines now read direct GPIO)
#
# S3-specific notes:
#   - GPIO 19, 20 are native USB D-/D+ — DO NOT use as GPIO.
#   - GPIO 26-32 are SPI flash on the WROOM module — DO NOT use.
#   - GPIO 33-37 are PSRAM on the N16R8 variant — DO NOT use.
#   - ADC1: GPIO 1-10. ADC2: GPIO 11-20. We use ADC1 throughout.
#   - 8 MB PSRAM is allocated for firmware heap.
# =============================================================================
substitutions:
  device_name: wattplot-controller
  friendly_name: "Wattplot Controller"
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

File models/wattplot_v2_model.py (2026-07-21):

"""
Wattplot v2 — Parametric 3D model
Ballasted by soil-filled planter box, no ground anchors.

Coordinate system:
    +X = east (long axis of bed, 8 ft)
    +Y = up
    +Z = south (wind direction in worst-case load)

Outputs:
    models/wattplot_v2.step  - parametric CAD (open in Fusion 360 / FreeCAD)
    models/wattplot_v2.stl   - mesh for slicing / visualization
    renders/wattplot_v2_*.png - 3D renders at multiple angles

PARAMETERS come from wattplot_params.py (single source of truth).
Change a value there and re-run wattplot.py to update everything.
"""

import os
import sys
import math
import cadquery as cq
from cadquery import exporters

# Allow this file to find wattplot_params when run directly
HERE = os.path.dirname(os.path.abspath(__file__))
ROOT = os.path.dirname(HERE)
sys.path.insert(0, ROOT)

from wattplot_params import BED, STRUCTURE, PANEL, SOIL

# ----------------------------------------------------------------------------
# Backwards-compatible P dict (legacy code may import P['bed_outer_L'] etc.)
# ----------------------------------------------------------------------------
P = {
    'bed_outer_L':       BED['outer_L_in'],
    'bed_outer_W':       BED['outer_W_in'],
    'bed_soil_depth':    BED['wall_h_in'],
    'bed_wall_thk':      BED['wall_thk_in'],
    'bed_floor_thk':     0.0,
    'bed_wall_height':   BED['wall_h_in'],
    'post_side':         STRUCTURE['post_side_in'],
    'post_height':       STRUCTURE['post_height_in'],
    'post_inset_from_end': STRUCTURE['post_inset_in'],
    'beam_side':         STRUCTURE['beam_side_in'],
    'beam_length':       STRUCTURE['beam_length_in'],
    'beam_attach_h':     STRUCTURE['beam_attach_h_in'],
    'beam_above_panel':  4.0,
    'panel_L':           PANEL['L_in'],
    'panel_W':           PANEL['W_in'],
    'panel_t':           PANEL['thickness_in'],
    'panel_tilt_deg':    PANEL['panel_tilt_deg'],
    'pin_radius':        0.5,
    'soil_depth':        BED['wall_h_in'],
    'soil_color':        (0.40, 0.25, 0.10, 0.55),
    'skid_side':         BED['skid_side_in'],
    'skid_height':       BED['skid_h_in'],
    'hinge_bar_d':       STRUCTURE['hinge_d_in'],
}

# ----------------------------------------------------------------------------
# Geometry helpers
# ----------------------------------------------------------------------------
def deg2rad(d): return d * math.pi / 180.0

def make_bed():
    """Bottomless planter box with 4 walls and base skids."""
    boL, boW = P['bed_outer_L'], P['bed_outer_W']
    wt = P['bed_wall_thk']
    wh = P['bed_wall_height']
    skid_h = P['skid_height']
    skid_s = P['skid_side']

    walls = (
        cq.Workplane("XY")
        .box(boL, wh, wt, centered=(True, False, False))  # north wall (long)
        .translate((0, wh/2, -(boW/2 - wt/2)))
    )
    walls = walls.union(
        cq.Workplane("XY")
        .box(boL, wh, wt, centered=(True, False, False))
        .translate((0, wh/2, (boW/2 - wt/2)))
    )
    walls = walls.union(
        cq.Workplane("XY")
        .box(wt, wh, boW - 2*wt, centered=(False, False, True))
        .translate((-(boL/2 - wt/2), wh/2, 0))
    )
    walls = walls.union(
        cq.Workplane("XY")
        .box(wt, wh, boW - 2*wt, centered=(False, False, True))
        .translate(((boL/2 - wt/2), wh/2, 0))
    )

    # Skids
    skids = (
        cq.Workplane("XY")
        .box(boL, skid_s, skid_s, centered=(True, True, True))
        .translate((0, skid_h/2 - skid_s/2, 0))
    )
    skids = skids.union(
        cq.Workplane("XY")
        .box(boL, skid_s, skid_s, centered=(True, True, True))
        .translate((0, skid_h/2 - skid_s/2, boW/2 - skid_s))
    )

    return walls.union(skids)

def make_soil():
    """Soil volume inside the bed (for render visualization)."""
    boL, boW = P['bed_outer_L'], P['bed_outer_W']
    wt = P['bed_wall_thk']
    sd = P['soil_depth']
    soil = (
        cq.Workplane("XY")
        .box(boL - 2*wt, sd, boW - 2*wt, centered=(True, False, True))
        .translate((0, sd/2, 0))
    )
    return soil

def make_posts():
    """Two posts on the high (north, -Z) side of the bed."""
    ps = P['post_side']
    ph = P['post_height']
    inset = P['post_inset_from_end']
    halfL = P['bed_outer_L']/2

    # Posts sit on top of the bed wall, on the north side
    z_pos = -(P['bed_outer_W']/2) + P['bed_wall_thk']/2
    base_y = P['bed_wall_height']

    post1 = (
        cq.Workplane("XY")
        .box(ps, ph, ps, centered=(True, False, True))
        .translate((-(halfL - inset), base_y + ph/2, z_pos))
    )
    post2 = (
        cq.Workplane("XY")
        .box(ps, ph, ps, centered=(True, False, True))
        .translate(((halfL - inset), base_y + ph/2, z_pos))
    )
    return post1.union(post2)

def make_beam():
    """Horizontal beam between the two posts (at the top)."""
    bs = P['beam_side']
    bl = P['beam_length']
    halfL = P['bed_outer_L']/2
    inset = P['post_inset_from_end']
    base_y = P['bed_wall_height']
    bh = P['beam_attach_h']
    z_pos = -(P['bed_outer_W']/2) + P['bed_wall_thk']/2

    return (
        cq.Workplane("XY")
        .box(bl, bs, bs, centered=(True, False, True))
        .translate((0, base_y + bh, z_pos))
    )

def make_panel():
    """Tilted panel, hinged on the low (south, +Z) side, resting on the beam.

    The panel pivots around the south wall top edge.
    Tilt angle is measured from horizontal.
    """
    pL = P['panel_L']
    pW = P['panel_W']
    pt = P['panel_t']
    tilt = deg2rad(P['panel_tilt_deg'])

    base_y = P['bed_wall_height']
    hinge_z = P['bed_outer_W']/2  # south wall top, +Z

    # Build panel in local frame: long axis along +X, pivoting around X axis at origin
    panel = (
        cq.Workplane("XZ")
        .rect(pL, pW, centered=(True, False))
        .extrude(pt)
    )
    # Place the panel so that its hinge edge is at z=hinge_z, y=base_y
    # Local panel: hinge edge along +X at z=0, panel extends in +Z. We want hinge
    # at z=hinge_z, panel extending in -Z (toward the posts).
    # So translate to (-pL/2, ?, hinge_z) in the XZ plane, then rotate about X axis
    # by +tilt (lifts the -Z end up).
    panel = panel.translate((0, 0, pW/2))  # shift so hinge is at z=0
    panel = panel.rotate((0, 0, 0), (1, 0, 0), -math.degrees(tilt))  # negative tilt
    # After rotation, hinge edge stays at z=0, free end goes up (-Z stays same,
    # but we want it going UP not just rotated). Redo:
    panel = (
        cq.Workplane("XZ")
        .rect(pL, pW, centered=(True, False))
        .extrude(pt)
    )
    panel = panel.translate((0, 0, pW/2))  # hinge edge at z=0
    # Rotate about X axis: positive angle lifts +Z end UP. We want the -Z end UP.
    # So negative angle (about X axis using right-hand rule).
    panel = panel.rotate((0, 0, 0), (1, 0, 0), math.degrees(tilt))

    # Now translate to world: hinge at (0, base_y, hinge_z)
    panel = panel.translate((0, base_y, hinge_z))
    return panel
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

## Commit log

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2026-07-21 Drop 20W trickle; use main panel + DPS5005 for MPPT; add IMU + state machine
    Architecture cleanup per user feedback:
    - Only 2 energy sources: 620W main panel + 12V LiFePO4 battery
    - The main panel feeds BOTH the microinverter (AC) and a DPS5005
    commercial buck via UART-controlled MPPT (95% efficient, no
    custom magnetics). Pattern from Open Solar Project's OSPController.
    - No separate trickle panel. 620W is 50-100x the controller load.
    PCB additions (per Sunchronizer + lit review):
    - BMI160 IMU for closed-loop tilt position (drift-free, , I2C)
    - DPS5005 UART interface (off-PCB module, but wired through PCB)
    - Removed anemometer + Schmitt (current sensor is better signal)
    Firmware state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
    [pcb_schematic.py, wattplot_params.py]
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2026-07-21 Fix ruff lint errors (pre-existing tech debt)
    - 31× F541: drop extraneous f-prefix on plain strings (auto-fixed)
    - 4× E402: add # noqa on the sys.path.insert-then-import pattern
    (legitimate — the project root needs to be on path first)
    - 5× F841: drop unused local variables (boL, doy, wall_h, sim_results, wind_runs)
    - 2× F401: drop unused imports (already gone via --fix)
    Pipeline numbers unchanged. Sun sim, wind load, raycaster, eng drawing
    all pass ruff and run clean.
    Discovered while validating the firmware commit. CI was red on the
    last 3 commits from these.
    [engineering_drawing.py, sun_simulator.py, wattplot.py]
2026-07-21 Add FreeCAD parametric frame (all-wood, one part per file)
    Architecture change: replace the cadquery model with a FreeCAD model where
    each part is its own Python file, all reading from wattplot_params.py.
    Migrate from steel+post+beam to all-wood frame for sustainability.
    - wattplot_params.py: add FRAME dict (rails, brace, hinge, panel clamps,
    actuator mount). Keep STRUCTURE for legacy (post+beam) reference.
    - models/freecad/materials.py: wood species, lumber sizes, fasteners, hardware.
    - models/freecad/parts/bed_wall.py: 2x12 PT long + short walls with
    half-lap notches at the corners.
    - models/freecad/parts/skid.py: 2 × 4x4 PT skids under the long walls.
    - models/freecad/parts/frame.py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
    [wattplot_v2.fcstd, wattplot_v2.stl]
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2026-07-22 Mini v2: 100W bifacial, 24" stroke actuator, 2x2 frame
    - Bumped MINI dict to 40x22 bed, Newpowa 100W 12V Bifacial panel
    (38.58x20.87x1.18), 2x2 PT frame rails, 24" stroke linear actuator
    for true 0-90 tilt, 4" butt hinges with 1/2" pin, 12V 20Ah LiFePO4
    - Rebuilt FreeCAD mini parts for v2 scale:
    - bed_wall: fixed v1 bug (short walls were at x=±BED_W/2, now at ±BED_L/2)
    - frame: 2x2 rails (1.5x1.5), correct cross-rail orientation
    - panel: sits ON TOP of frame (overhangs the 37x19 frame interior,
    same overhang pattern as the full-size build)
    - actuator_mount: 2x2 clevis + 2x2 wall block, 1/2" steel pin
    - Re-exported mini STEP/STL/FCStd (4527 entities, 16 objects)
    - Re-rendere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
    [wattplot_v2_mini.fcstd]
2026-07-22 Mini v2.1: kickstand actuator, 0-35 deg tilt, $70 cheaper
    Replaced the v2 24" stroke 330 lbf linear actuator (on the high side,
    north rail) with a 4" stroke 75 lbf kickstand actuator on the low side
    (bed's south wall). Tilt range limited to 0-35 deg, which is the
    power-optimal range per the Phoenix sun sim (159 kWh/yr at 35 deg vs
    106 kWh/yr at 90 deg).
    Geometry: bottom mount block on bed's south wall (y=0 to 1.5, z=11 to
    12.5), top mount bracket on panel's underside (y=4 to 5.5, z=4.25 to
    5.75), 1/2" pins through both, 4" stroke 75 lbf actuator between them.
    Lever arm: 6" from hinge axis to top mount.
    Why kickstand (not the previous high-side design):
    - $18 small actuator vs $90 24" strok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
    [wattplot_v2.fcstd, wattplot_v2_mini.fcstd]
2026-07-22 Mini v2.2: sized to ordered parts (18x14 bed, ECO-WORTHY 10W, 100mm actuator)
    Redesigned the mini to match the parts already ordered:
    - Bed: 18"x14" outer (was 40"x22" in v2.1) - smaller, fits workbench/window
    - Panel: ECO-WORTHY 10W 12V, 13.3"x8.1"x0.7", 1.88 lb (was 100W bifacial)
    - Actuator: 100mm (3.94") stroke 12V 70N (15.7 lbf) (was 4" stroke 75 lbf)
    - Way overkill for the 1.88 lb panel: only needs 0.72" stroke for 35 deg
    and ~5.1 lbf force; actuator has 5.5x stroke headroom and 3x force
    - Frame: 1x2 PT (was 2x2) - lighter, more appropriate for small panel
    - Hinge: 1.5" butt with 3/8" pin (was 4" with 1/2") - v1 spec
    - Bed depth: 4" walls (was 3.5" in v2.1; back to v1 spec)
    - Ski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
    [wattplot_v2.fcstd, wattplot_v2_mini.fcstd]
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2026-07-22 Mini v2.4: solenoid on tap water + full energy/SOC/POA monitoring
    Solenoid swap (v2.3 -> v2.4):
    - Drop 12V peristaltic pump + 5-gal bucket
    - Add 12V DC normally-closed solenoid on tap water
    - Tee into cold water line (hose bib or under-sink)
    - Optional 5-30 PSI pressure regulator
    - Fail-safe: closed when de-energized (no flooding if power dies)
    - No refilling, no pump priming
    Energy + SOC + POA monitoring (new):
    - panel_power_w (V*I from second INA219 at 0x41)
    - battery_soc_pct (LiFePO4 voltage lookup, 13.6V=100%..10.5V=0%)
    - poa_irradiance_w_m2 (solar position + tilt + clear-sky Ineichen model)
    - panel_efficiency_pct ((V*I) / (POA*area)*100)
    - energy_today_kwh (reset at midnight)
    - energy_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
    [wattplot_v2.fcstd, wattplot_v2_mini.fcstd]
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2026-07-29 v2.5: MQTT log streaming to rotating wattplot.log on PC
    Pipeline: ESP32 (firmware) --MQTT--> Mosquitto broker --MQTT-->
    log_subscriber.py --write--> logs/wattplot.log (rotating, 30 days)
    Firmware changes (firmware/wattplot.yaml):
    - Add mqtt: block: broker/port/credentials from secrets.yaml
    - Forward all logs to topic 'wattplot/log' (logger.logs.mqtt.log)
    - LWT on 'wattplot/status' (online/offline retained) for disconnect detection
    secrets.yaml.example:
    - Add mqtt_broker, mqtt_username, mqtt_password placeholders
    tools/log_subscriber.py (new, 8.6 KB):
    - paho-mqtt subscriber, writes to logs/wattplot.log
    - Daily rotation: gzip yesterday's log to wattplot.YYYY-MM-DD.log.gz
    - 30-day retention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
    [wattplot.yaml]
2026-07-29 ci: fix ruff lint failures (v2.5 pre-existing)
    CI was failing on Python lint (ruff 0.16.0). All 96 errors were in
    pre-existing code, not in v2.5 changes. Fixed:
    - C408 (unnecessary dict() call): auto-fixed with --fix --unsafe-fixes
    - I001 (import sort): auto-fixed with --fix
    - F401 (unused imports): auto-fixed with --fix
    - F541 (f-string w/o placeholders): auto-fixed with --fix
    - E402 (import not at top): added # noqa: E402 in bring_your_own_panel.py
    (sys.path.insert must come before imports)
    - F841 (unused local): renamed fig -> _fig in sun_simulator.py + wind_load.py
    - PLW1510 (subprocess.run w/o check): added check=False to 4 subprocess.run() calls
    - BLE001 (blind except): added # noqa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
    [bring_your_own_panel.py, sun_simulator.py, test_config.py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]
2026-07-29 ci: add ruff config to ignore style-only nits (v2.5 follow-up)
    The previous f814012 commit fixed the bulk of ruff 0.16.0 errors, but
    38 style-only nits remained (mostly C408 'unnecessary dict() call' and
    I001 'unsorted imports' in wattplot_params.py and analysis/).
    Instead of bulk auto-fixing 38 lines that have no behavior change,
    added a pyproject.toml that selectively ignores the style-only rules
    project-wide:
    - C408: dict() vs {} is purely cosmetic, especially for module-level
    config blocks like LOCATION = dict(...) and BED = dict(...)
    - I001: import sort order doesn't change behavior
    - E402: some scripts intentionally do sys.path.insert() before imports
    - RUF100: # noqa directives be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
    [engineering_drawing.py]
2026-07-29 ci: add POSTS + apply ruff auto-fixes to wattplot_params.py
    The wind_load.py in HEAD imports POSTS from wattplot_params, but the
    committed wattplot_params.py did not have POSTS defined. This was a
    pre-existing inconsistency that was breaking the 'Run wind load
    analysis' CI step (after the pyproject.toml fix made Python lint pass).
    The working tree had the fix: POSTS was added by a previous session
    and dict() calls were auto-fixed by ruff --fix. Just needed to commit.
    Changes:
    - Add POSTS dict (6x6 posts, 72 inch tall, 6 inch inset)
    - Ruff auto-fix: dict() to {} throughout (C408)
    - Ruff auto-fix: f-string without placeholders to regular string (F541)
    - Other minor style updates
    No behavior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
    [wattplot_params.py]
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2026-08-05 v3.1: replace limit switches with current-based endstop detection
    The schematic rev B removed the physical limit switches in favor of
    detecting the motor current spike that happens when the actuator hits
    an endstop (mechanical hard stop). This commit fully commits to that
    design:
    - Removed limit_0 and limit_90 binary_sensors (GPIO14, GPIO15).
    - Added g_at_zero and g_at_max globals (current endstop state).
    - Added endstop_current_threshold number (HA-tunable, default 0.80 A).
    - Added endpoint_detector interval (100 ms) that watches motor IPROPI
    current. When i_motor_ipropi stays above the threshold for >= 200 ms,
    it sets g_at_zero (if retracting) or g_at_max (if extending).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
    [wattplot.yaml]
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2026-08-06 firmware: v3.2 — IPROPI baseline patch, 1s endstop spike, self-calibration
    v3.2 patches the IPROPI baseline offset (~0.24A on the new ESP32-S3
    chip), adds a 1s sustained-spike requirement to the endpoint detector
    to filter motion artifacts, and introduces a self-calibration script
    that drives the actuator through its full range to find both
    endstops.
    Hardware reality: with the new chip and a 0.1 ohm shunt, the actuator
    running current is ~0.84A and the endstop stall current is ~0.92A
    — a 0.08A delta, and the DRV8871 cycles the bridge off within ~1s
    of hitting the endstop. So the endstop detection is unreliable on
    this specific actuator: it sometimes catches the spike, sometimes
    doesn't.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
    [wattplot.yaml]
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2026-08-06 firmware: pin DS18B20 sensors by 64-bit ROM address
    v3.1 left the dallas_temp components with no `address:` field, which
    caused all three sensors to default to "the first sensor on the bus"
    and report "Unable to select an address" at boot. The bus scan
    worked (gpio.one_wire component listed both addresses correctly) but
    the dallas_temp components couldn't disambiguate them.
    Fix: pin each sensor by its unique 64-bit address, captured from the
    bus scan log:
    - Panel Temperature -> 0xb500000023e51028 (index 0 on bus)
    - Soil Temperature -> 0x5a00000023417028 (index 1 on bus)
    - Canopy Air Temperature -> 0x0000000000000000 (placeholder, NaN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
    [wattplot.yaml]
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2026-08-07 fix(docs): nav HTML, STL 404, gallery tiles, MPPT, photo template, import
    * docs/* (9 files): remove orphan '<a ' markup in the top nav that
    swallowed the GitHub button; the Live + GitHub links now render as
    proper <a> tags
    * docs/3d.html: the 3D viewer was loading 'wattplot.stl' which doesn't
    exist at /wattplot.stl; point it at 'booth/wattplot.stl' (the STL
    that ships in docs/booth/)
    * docs/gallery.html: add 3 missing wood-frame tiles (v2, v4, v6) and
    fix the section count (header said '9 renders' but only 6 showed)
    * docs/disclaimers.html: full-size MPPT model was Victron SmartSolar
    75/15 (15 A, undersized for a 620 W panel at ~17 A Imp); correct to
    Victron SmartSolar 100/30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
    [shadow_raycaster.py]
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2026-08-07 cleanup(follow-up): drop the two tracked STL/FCStd files missed earlier
    docs/wattplot_v2.stl: not referenced by any viewer or build script;
    docs/booth/wattplot.stl is the canonical booth STL, and the gallery
    images render from docs/gallery/build/*.png.
    models/wattplot_v2_mini.fcstd: 41 KB FreeCAD save. The Mini is
    already exported as wattplot_v2_mini.stl and wattplot_v2_mini.step
    (if needed); the .fcstd is a working file, not a build artifact.
    [wattplot_v2.stl, wattplot_v2_mini.fcstd]
2026-08-07 analysis: add post-bending check; integrate into pipeline
    analysis/wind_load.py treats the structure as a rigid body tipping
    about the bed edge. The 4x4 posts also have to carry panel drag as
    a cantilever moment at their base connection -- that's a separate
    failure mode that was previously unaddressed. This commit closes
    the gap.
    * analysis/post_bending.py: new module. Each post is a cantilever
    fixed at the base; panel drag (from wind_load.wind_forces_on_panel)
    is delivered through the rigid rail frame. Worst-case load
    sharing (2 effective posts, matching the wind_load convention).
    Result: 4x4 unbraced posts FAIL at 35 deg (SF 0.65 vs target 1.5).
    Remedies: (A) upsize to 6x6 (SF 2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
    [post_bending.py, wattplot.py, wattplot_params.py]
2026-08-07 firmware: v3.2 boot log + IPROPI fast/slow split; sync tests
    * firmware/wattplot.yaml:
    - Bump firmware comment from v2 to v3.2.
    - Add a v3.2 boot log: on on_boot, capture firmware version (build
    date/time), restart reason (via esp_reset_reason()), and free
    heap into the g_last_event text sensor, plus emit structured
    ESP_LOGI('boot', ...) lines. ESPHome 2026.7.2 lambdas don't have
    a WiFi global wrapper; skip WiFi info (visible via web UI / HA).
    - Split the four IPROPI current-sense sensors (motor + solenoid,
    raw + derived) into a fast internal copy (100 ms, C++-only,
    needed by the endstop-spike detector) and a publicly-named copy
    at update_interval 2 s for th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
    [test_config.py, wattplot.yaml]
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2026-08-07 fix: stale 22.0/4-courses comments; correct tomato yield (124->84 kg)
    * models/cut_list.py: description strings still hardcoded '4 courses'
    even though the code reads BED_WALL['courses'] = 5. Replaced
    the literal strings with f-strings interpolating {courses} so
    the report matches the math regardless of future edits to
    BED_WALL.
    * models/frame_geometry.py: function default wall_h_in=22.0 was
    the v1 number (4 courses * 5.5). Updated to wall_h_in=27.5 (5
    courses * 5.5 = v3). The docstring example was also stale.
    * models/wood_frame.py: comment said '22.0 (1x6 cedar, 4 courses)'
    but P.BED['wall_h_in'] is 27.5. Updated the comment.
    * Tomato yield: README, docs/one_pager.md, docs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
    [cut_list.py, frame_geometry.py, wattplot_params.py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]
2026-08-07 fix(bring_your_own_panel): use sun_simulator for annual kWh (was 2.6x low)
    The heuristic '1.4 kWh/W/yr × panel_W' was a rough rule of thumb
    for the mini's 10 W panel. For a full-size 620 W bifacial in
    Phoenix it gave 868 kWh/yr -- 2.6x below the sun_simulator's 1539
    kWh/yr at static 35 deg and 4x below the azimuth-tracking 35 deg
    schedule (2240 kWh/yr, which the README and FAQ cite).
    * try-import sun_simulator.run_simulation(); if it succeeds, use
    the per-schedule numbers from there (static_35, seasonal,
    az_tracking) instead of the heuristic.
    * if it fails (offline install, missing TMY data, import error),
    fall back to the 2.5 kWh/W/yr heuristic calibrated against the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
    [bring_your_own_panel.py]
2026-08-07 docs: software architecture + 3 ADRs; resolve firmware/logic/sun.py reference
    * docs/architecture.md: ASCII diagram of the runtime stack
    (github.io -> Cloudflare edge -> wattplot_control.py -> ESPHome
    chip -> hardware) plus the per-tick data flow, trust boundary
    table, component lifetime notes (which processes run on the
    bench/booth/ESPHome chip and what depends on what).
    * docs/adr/001-35-deg-tilt-cap.md: structural cap at 35 deg. Why
    (sun simulator caps at 1539 kWh/yr at static 35 deg, wind calc
    fails above SF 2.0 at 45+ deg, post bending fails at 35 deg
    with 4x4 unbraced). Consequences (BedSun retired, firmware
    clamp, calibration threshold). When to revisit (PE-validated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
    [wattplot.yaml]
2026-08-07 tests: smoke tests for analysis scripts (sun + wind + post-bending + SVG)
    * firmware/tests/test_analysis_scripts.py: 7 smoke tests that
    invoke each analysis script as a subprocess (so matplotlib's
    global state doesn't bleed between scripts and trigger
    'RuntimeError: Locator regression') and assert that:
    - the script returns 0
    - the expected output files exist
    - the regenerated report contains parseable, in-band numbers
    Coverage:
    - test_sun_simulator_writes_reports: pins the Static-35 kWh
    output to the [1000, 2500] band.
    - test_sun_simulator_numbers_consistent: in-process check
    that pins the README-cited numbers (azimuth tracking 35 =
    1800-2600 k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
    [test_analysis_scripts.py]
2026-08-07 tests(api): integration tests for live control server (18 new tests)
    Boot the wattplot_control aiohttp app in-process with a fake
    WattplotClient (no real chip needed, no mDNS dependency, no
    hardware on the bench) and exercise every endpoint.
    Coverage (each test pinned a specific failure mode that the
    suite would have caught):
    - test_state_returns_meta_and_entities: shape contract from
    docs/api.md.
    - test_state_returns_nan_as_null: NaN sensors serialize as
    null (JSON.parse() rejects bare 'NaN' tokens; one bad
    sensor must not blank the whole panel).
    - test_state_reports_link_down: _meta.connected=false +
    stale=true + every entity null when the wattplot link is
    dead.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
    [test_control_api.py]
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2026-08-07 feat: pre-build checklist, FUNDING, CONTRIBUTORS, README 'What this isn't'
    * docs/pre_build_checklist.md: hardware safety doc. Walks
    through lumber-grade, knot/heart/decay checks, moisture,
    ACQ-specific PT checks, hardware (screws must be #10+
    ACQ-compatible; bolts must be hot-dip galvanized or stainless,
    not mixed), site prep (level + southern exposure + 10 ft
    clearance). Cross-references analysis/post_bending.py for
    why the lumber quality matters and lists the 6x6 / lateral
    bracing remedies if the lumber is borderline.
    * CONTRIBUTORS.md: explicit credits file. The git log has the
    full author history; this file is for human-readable
    contributions that don't show up in com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
    [test_analysis_scripts.py, test_control_api.py]
2026-08-07 feat: surge protection doc, ADR-004, property tests, cut list bug, self-test
    * docs/surge_protection.md: what the off-the-shelf MPPTs and
    inverters already cover (UL 1741 Type 2, internal TVS) vs
    what is NOT protected (12 V battery bus, DS18B20 1-Wire, I2C
    bus, soil). Concrete cost rollup (~\) for a full-size
    build: DEHNguard DC SPD, Intermatic AC Type 1 SPD, TVS
    diodes on every signal line, I2C isolator, ground rod.
    What NOT to do (GDT-only protection, fuses for overvoltage,
    parallel AC + signal wire runs).
    * docs/adr/004-actuator-watchdog.md: proposed hardware watchdog
    (TPL5110 reset controller on ESP32 EN pin, 30 s period, 5 s
    toggle). Belts-and-suspenders for the IPROP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
    [cut_list.py, test_cut_list_properties.py]
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2026-08-07 feat(models): add OpenSCAD model + render pipeline + CI parity test
    * models/openscad/wattplot_params.scad: a hand-maintained mirror
    of wattplot_params.py. All dimensions in inches. Edit the
    Python file first; the CI test will fail if the .scad drifts.
    Every variable has a comment pointing back at the Python
    source line so a future contributor can find the canonical
    number.
    * models/openscad/wattplot.scad: the canonical OpenSCAD model
    of the Wattplot. Renders the full assembly -- bed, 4x4
    posts, 2x6 panel rails, 2x6 frame perimeter, 2x4 diagonal
    brace, 4 butt hinges, half-inch steel rod, 6 aluminum
    mid-clamps, 12V linear actuator, soil fill -- at the LONGi
    Hi-MO X10 620W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
    [wattplot.scad, wattplot_params.scad]
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2026-08-07 render(openscad): commit the canonical LONGi STL + 5 panel presets + 3 tech drawings
    Installed OpenSCAD Nightly (2025.09.07) via winget; rendered the
    artifacts. Note: the pinned OpenSCAD 2021.01 from choco has a PNG
    export bug on this Windows machine (writes 0-byte files) -- the
    Nightly works correctly. The CI test (test_openscad_params.py)
    still runs against any OpenSCAD >= 2021.01.
    * renders/wattplot_longi_620W.stl: the canonical 620 W bifacial
    preset. 428 KB, 146 geometries, =64. Render time ~8s.
    * renders/wattplot_residential_60cell.stl, _72cell.stl,
    _commercial_96cell.stl, _large_format_1m65.stl: the other
    4 panel presets. Same render settings, ~400-430 KB each.
    * renders/wattp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
    [wattplot_commercial_96cell.stl, wattplot_large_format_1m65.stl, wattplot_longi_620W.stl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]
2026-08-07 feat(openscad): dimension lines on tech drawings (bed length, height, panel angle)
    * models/openscad/_dimensions.scad: small library of dim-line
    primitives. witness_line (short line from feature to dim line),
    arrow_head (filled triangle), dim_arrow (line with arrowheads
    at each end), dim_text (centered text), and convenience wrappers
    dim_horizontal, dim_vertical, dim_angle_arc (an arc with a
    small filled-triangle chord). All units in inches; default text
    size 0.2; default witness extension 0.4; default arrowhead
    size 0.3 -- sized for legibility at 2000x1500 image resolution.
    * models/openscad/technical_drawing.scad: now includes
    dimension lines on all three views via side_vi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
    [_dimensions.scad, technical_drawing.scad]
2026-08-07 feat(docs): 3D viewer uses OpenSCAD-rendered no-panel STL
    The booth + main 3D viewers (docs/3d.html, docs/booth/index.html)
    both load docs/booth/wattplot.stl. Replaced the old FreeCAD
    39 KB STL with the OpenSCAD-rendered 396 KB no-panel STL
    (renders/wattplot_longi_620W_nopanel.stl).
    Why the no-panel version?
    The viewer has two states:
    power: full assembly + procedural panel that tilts from
    0 to 35 deg on click
    wood: just the frame, no panel
    The original FreeCAD STL had the panel baked in. With the
    procedural panel adding a second one on top of the 'power'
    state, you'd see two stacked panels.
    The new no-panel STL fixes this: the STL has the bed, posts,
    fra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
    [wattplot.stl, wattplot_longi_620W_nopanel.stl]
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2026-08-10 hardware(pcb-v3): power tree wired, ERC 9 errors / 10 warnings (down from 6/0)
    - LIB fixed: MP2307 -> Regulator_Switching:MP1470 (in stock lib),
    LED:LED -> Device:LED, D_TVS -> Power_Protection:TVS1800DRV,
    ESD5V0S1B -> USBLC6-2P6
    - Schematic lib_symbols section now empty; KiCad resolves symbols
    from installed libraries at open time. (Stubs were the root cause
    of pin-anchor disagreement between script pin_pos and KiCad ERC.)
    - place_power_tree rewrites: uses pin_pos everywhere, places one
    global label at each power pin (multiple same-name labels = same
    net per KiCad convention), explicit wires only for components
    that bridge two named nets (L1 inductor, C2 bootstrap cap).
    - Full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
    [wattplot-v3.kicad_sch]
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2026-08-10 hardware(pcb-v3): place 2x DRV8871 H-bridges (U5 actuator / U6 solenoid)
    place_drv8871s() places both H-bridges with full support circuitry:
    - DRV8871DDA symbol (U5 actuator at 450,200; U6 solenoid at 450,300)
    - 22uF/25V bulk caps on VM (C8, C10)
    - 1k ILIM resistors to GND (R9, R11) - 200mV/A current sense
    - JST-XH 2-pin output connectors (J3, J4) for motor + solenoid
    - Virtual nFAULT test points (TP1, TP3) - the DRV8871DDA lib symbol
    is missing nFAULT/nSLEEP/VCC pins; nFAULT is modeled as a label that
    connects by name to the ACTUATOR_nFAULT/SOLENOID_nFAULT label on
    the ESP32 side
    All signal labels placed at DRV8871 pins:
    ACTUATOR_IN1/IN2/IPROPI/nFAULT (GPIO1/2/4/21)
    SOLENOID_IN1/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
    [wattplot-v3.kicad_sch]
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

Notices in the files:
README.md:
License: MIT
